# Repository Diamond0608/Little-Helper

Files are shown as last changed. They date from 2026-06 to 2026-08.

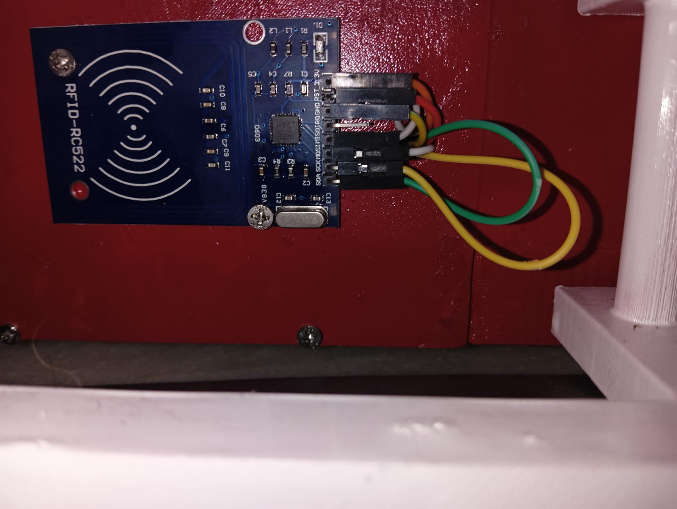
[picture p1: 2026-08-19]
Photos/WhatsApp Image 2026-08-15 at 8.00.09 PM.jpeg

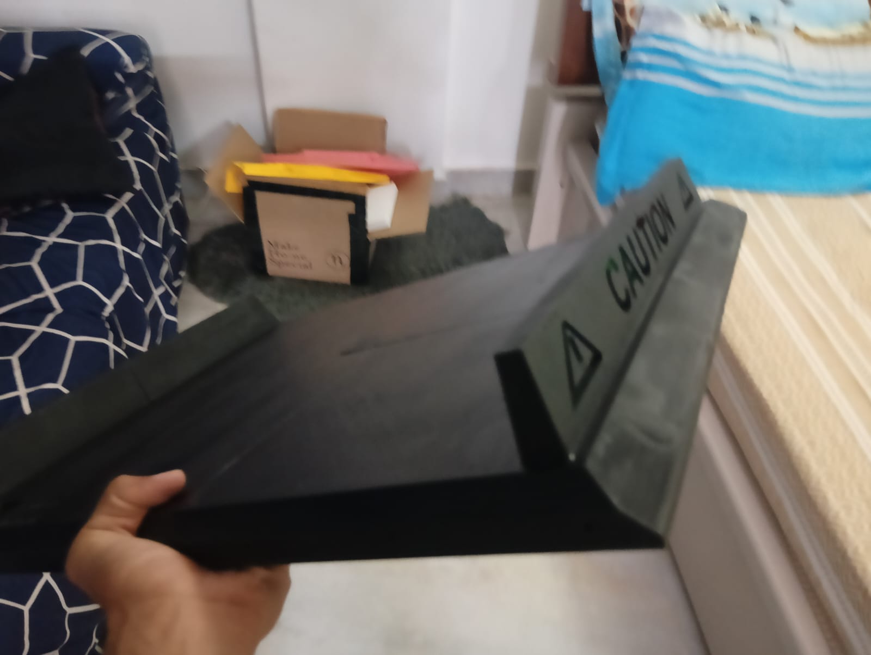
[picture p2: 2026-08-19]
Photos/WhatsApp Image 2026-07-06 at 4.40.42 PM (2).jpeg

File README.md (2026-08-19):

# LITTLE HELPER:
## DOCUMENTATION
<p align="center">
  Littlehelper3
  &nbsp;
  Littlehelper
  WhatsApp Image 2026-08-17 at 5 44 37 PM
  WhatsApp Image 2026-08-17 at 5 44 32 PM
</p>

## Basic Questions and Overview:

### What is Little Helper?

Little Helper is a track based 4wd bot that is capable of  moving around with a giant box on top of it so that teachers can carry books and papers, although it could be used for other purposes as well! As of right now it is controlled via a PS3 controller (you could also use a phone to control it if you tweak the code). I plan to eventually add autonomous capabilities but that is not currently available.
You can find a demo of the bot here: https://youtu.be/gsAc9kgTfto
<p align="center">
  WhatsApp Image 2026-08-17 at 5 44 36 PM
</p>

### Why did I make this project?

A while back after a robotics competition called the National Robotics League, a teacher saw our robot moving blocks around and jokingly asked, could you make it move the textbooks from class to class? We laughed it off, but when I was preparing an idea for Fallout - a Hack Club program, I thought why not actually do that? I love building bots that can drive and it would actually be usefull. (Note this project was submitted to Hack Club's Beest Program, not fallout).

### Use case:
The bot has an A3 sized box on top and a set of tank tracks that help move it, but the bot could very easily be retrofitted to other purposes as well. For example an all terrain bot would also be a valid use case due to the tank tracks. The tank tracks also make it easy to climb stairs or other unusual surfaces (keep in mind the stairs can't have too much height), however, the current version of this bot is unable to climb stairs due to the front plate being too long but I am working on making a new version of the bot that has a much better design, the motors I've used are highly powerful and have really good torque as well, so it would be a good recreation/racing bot perhaps (bear in mind that the bot would be on the heavier side). It could also be used to pull or push objects should you want. (The only limit here is your imagination realistically, the bot is kind off a base to build your ideas!)

### How long would it take me to build this?
The main issue with the building process would be acquiring the parts especially the 3d printed parts, however as for the rest of it, if you're following this guide to the T, a maximum duration should be around 35 hours, since I took that time period to build the project for the first time in R&D without any powertools.

### Can I buy this?
In a way. While the bot isn't available for purchase you can buy the parts and build it yourself! It honestly isn't that difficult even if you have very basic skills in regards to this. Another thing to bear in mind is that this is obviously not a lisenced or approved project, so there's no warranty and should you need regulatory authorisation/permission , you would need to reach out to the appropriate body yourself.

### Is it easy to build this?
Absolutely! The bot is actually quite basic, even the tank tracks are just held on by guiderails and friction. I'm not the most skilled individual so I couldn't make the project too difficult to build, which gives the benefit of an easy to make product. However, obviously it should be noted that this project's target group is enthusiastic tech people/ people getting into hardware.

### Is this all free?
YES! All the materials I've provided are open source, you can use, modify, or distribute them however you like, however please credit me for this build. Infact if you need any help with building this just send an email to me at : alvashlok@gmail.com and I'll try to help you out.

### How expensive is this?
The cost of building it is completely and elaborately detailed in the BOM ( Bill of Materials ) showcased in this repo, but the average cost would be around INR 22697.2 all inclusive, however bear in mind that if you can make the chassis yourself it would be significantly cheaper as all the components except for the chassis and tracks comes to INR 10197.2. The tracks could be DIY'd using bicycle tubing. More details on that are given in the build guide.

## Mapping and Functionality:

The code currently works in the following way: The left stick moves the bot forward and backwards, and the right stick lets you move sideways. The square button activates a buzzer, the O locks the bot, and X toggles the safety mechanism.

### Authentication:
The bot has a 2 factor authentication method- first you scan a keycard on an RFID scanner and then input a pin to gain access. The LCD screen guides you through this process and there are auditory beeps to help as well.
The O button on the controller locks the bot and forces you to authenticate again.
The controller even if connected is practically dead until authentication is completed. The bot starts in a locked state by default when turned on.

### Safety Mechanism:
The bot has an ultrasonic sensor mounted in the front that stops the bot if you are closer than 15 cm from an obstacle. The safety mechanism disables controls at that point and sounds the buzzer. The bot cannot be moved until the obstacle is removed. The safety can be turned off when X is pressed, but this will not work if an obstacle is already in the path of the bot. 

## Suggestions For Use:

1. Firstly if you plan for the robot to move up stairs, keeping CG in mind while loading stuff in the box would help (try to keep the books flat as otherwise not only would it move around but should they fall that may displace the bot). (CANNOT CLIMB STAIRS CURRENTLY)
   
2. The battery life won't be more than an hour (I've not tested this yet but it's an approximate). However installing a battery of higher amperage would be really easy ( Just don't change the voltage or if you do use a step down/step up converter).
  
3. The motor driver already has a very high current draw from the motors since they're 4*1000 RPM Johnson Grade A motors so be wary of installing components that would add to the current draw.

4. To conserve battery life removing components that are unnecessary for your use case is suggested. You can also change the code to tweak the speed of the bot (1000 RPM is the absolute max and the minimum would be whatever you want).

5. People should be aware of the bot's presence wherever you're using it so no one accidentally stays in its path or tampers with it.

6. If exam papers are being carried in the box, lock the box securely.

7. While you are free to use whatever parts you choose, avoid mecanum wheels as they won't fit onto the motors and they can't be used to their potential and as such are a waste of time, since it isn't possible to move sideways etc when using tracks which is the main point of mecanum wheels. Also the wheels may not grip the tracks well.

8. If you want to not use code and have a transmitter/receiver and want to save on parts, you could use an ESC to control your motors with a transmitter and receiver, however you would still need to keep an ESP for the other electronics, and there would be no scope for making the bot autonomous after this.

## The CAD File:

The CAD file can be found in this repository as both a STEP file and a f3d file ( I made the model in fusion ). 
<p align="center">
  Littlehelper5
Littlehelper7
</p>

### Basic Suggestions:

Wherever there are holes with fasteners like screws placed inside, I would recommend drilling the holes with a handhed drill if you have one available to you. If you don't have the access to one however, you can 3d print the part with the hole as a part of it, or as a DIY method that I sometimes use you could heat a sharp metal rod like a small poker used for melting marshmellows/making corn on the cob and then carefully make the hole where you need to (you may not get a tight fit or threading with this method so you may have to add nuts). All the screws are either M3 or M5 to make the process of building easier. IMPORTANT: This is designed to be changeable the motor driver holes I have provided should be adjusted to appropriate dimensions unless you're using the same motors. Similarly adjust all other mounts.

Something to note is that I did not add any spacers between the components and the plastic chassis in the CAD file, however, it's important to do that. Plastic spacers can be 3d printed or bought online as well.

While the CAD file does have 3d wiring, that is more to serve as a reference, there is no gaurantee that it will be accurate and as such please refer to the schematic diagram instead when you're doing the wiring.

Something else to note is that care should be taken while attempting to 3d print. If a part is too big for your 3d printer, I would suggest printing it in pieces and using the adhesive - Metlock 743 which practically makes it one component ( but be very careful with this adhesive as it is incredibly strong and even a drop bonds the plastic together permanently and you should wear a mask and safety goggles incase you see fumes from the plastic (also make sure that you aren't making some kind of toxic fume)). You could also CNC the chassis or make it from foamboard, the CNC version will be heavier however and the foamboard version would be weaker.

Also the tracks while modelled aren't designed to be 3d printed. Tracks should be made of a material like rubber for optimum grip, 3d printing it wouldn't work. I've also not modelled the linking mechanism well enough that you could take 1 link from the cad and just attach it to other links, you would have to glue it together.

Something very important is resizing the power button as per the dimensions of the one you purchase (if theres a large size difference) this has to be a 3d printed hole (you could make the hole yourself if you have the required power tools).

### General Info:

The CAD file has every component and body named for ease, some components/bodies are connecting wires and as such they are named with the origin and destination. This notation is important to note: BR- Back panel Right side, BL - Back panel Left side, FR - Front panel Right side, FL - Front panel Left side, LF - Left panel Front end, RF - Right panel Front end, LB- Left panel Back end, RB - Right panel Back side.

The hinges for the box are 3d modelled but they SHOULD NOT be printed, purchase those from a hardware shop, these hinges are not designed to actually work. I'd also suggest changing the text present on the chassis and box since they're highly customised to me, so it would make sense to change it to something that you want. You could use the timeline feature to find where I wrote the text and just change the text and the extrude should catch up after that operation is done. 

I know it sounds stupid to mention it but please don't try to 3D print any of the wires or electronic components either. 

There are a few joints that can be animated through the relationship page as well : The wheels rotate, the lid of the box opens and closes, the lock for the box opens and closes, and a few of the nuts also rotate.

The placement of most components in the CAD file is genuinely arbritary, you could change it as you please (Obviously would have to change the wiring and mounting points appropriately).

## Code:

The code can be tweaked however you want. Especially do change the configuration for the controls and how you connect your controller (you could keep the same controls if you wish but the controller connection won't transfer).

The code can be uploaded to the ESPs via Arduino IDE. Just make sure you select the appropriate port and board in the board manager, and ensure you have all the required modules installed and all the needed drivers. 

Its also possible to upload the code via VSC if you use PlatformIDE or other such extensions, so if that's something you want to do that is also possible.

There are 2 code files present, one for the ESP32 and one for the ESP8266, keep in mind that I personally AI generated this code and did not make it myself.

<p align="center">


</p>

## Building the Project: 

If you are using self-tapping screws note that the screws can get really hot as you drive them into the bot. I really recommend making the holes yourself with a drill. Note that I did the following tasks in a different order, so the photos may not match the instructions perfectly, in that case please follow the instructions instead of the photos. More photos of what I built can be found in the photos folder of this repo.

1. To start with refer to the BOM and ensure you have all the parts you require. ( You could start building with only some of the parts and adding parts as and when they come as well but workflow would become worse ).

<p align="center">


</p>

2. Step one would be to take your side panels and attach the motors to them. The motors have 3 holes in an L shape which can be matched to the side Chassis. Orient it in a way such that the motor shaft passes through the hole in the same way that in passes through on the opposite side (avoid difference between the sides since that would make the tracks uneven). 

<p align="center">
WhatsApp Image 2026-07-12 at 12 02 51 AM
</p>

3. Once that is done, attach the guidelines as per the screw holes at the center of the side panel. ( For the guidlines there's only a small surface area where there is a contact between it and the panel. 

<p align="center">
WhatsApp Image 2026-07-16 at 5 26 31 PM (2)
</p>

4. Next take the RFID reader, LCD screen and Numpad and place and secure them in the appropriate positions on the side panels. Note that the numpad isn't secured by screws as it has no scope for that due to its thickness and material. The numpad comes with adhesive on the back and it should be placed on the side panel.

<p align="center">
WhatsApp Image 2026-07-13 at 4 38 29 PM (2)

</p>

5. Take the battery and place it in the battery holder (if you changed the battery obviously change the battery holder as well unless it's the same configuration). Secure the cover as well. In my CAD file there is a canvas showing a fire hazard, I would suggest making a marking similarly whether with a marker or a sticker, or 3d printing an imprint or sticking a sheet of paper. 

<p align="center">
WhatsApp Image 2026-07-19 at 1 47 04 PM
</p>

6. Take the bottom panel and attach the battery holder (and the buzzer holder if that was printed seperately).

7. Attach the side panels on both sides to the bottom plate.

8. Now take the wheels and place them on the motor shafts such that the tire treads all point in the same direction and the hole on the tire for the bolt overlaps with the hole on the motor. Place the m3 bolt inside and secure it tightly (the wheels should not shake or come lose). A nut isn't needed for this bolt as the motor shaft has threading.

<p align="center">
WhatsApp Image 2026-07-14 at 4 28 41 PM (1)
</p>

9. Now comes the part that differentiates the bot from other regular 4wd bots. Take the purchased track chain and place it over the two tires on a side. These tracks have removable links, so add or remove the links to tension the track as tightly as you can. Remember that there is nothing holding the chain there except friction. So tighten it as much as you can without risking the chain snapping.
9.1 If you want to make the tracks yourself, simply purchase any regular bicycle tube and cut off the part where the nozzle is present. Once that is done you can wrap it around the wheels and adjust the length until its a very firm grip, but not firm enough that it may snap or is bending the wheels or motors (be very careful about this, you have to get an ideal tensioning). Then mark and cut the track and glue the ends together and mount it securely.

<p align="center">
WhatsApp Image 2026-07-16 at 5 26 31 PM (1)
</p>

10.  Great! Now you have your hollow shell, the next step would be wiring etc, before you close the top or front and back plates so that you can still easily access components. Bring the wiring for the components placed on the side panels through their respective holes. Then place the motor driver, ESP8266, and ESP32 in their respective positions. Attach the ultraonic sensor to the front panel on the mounting plate. Plop the buzzer into its holder as well (Don't attach power button yet).

<p align="center">
WhatsApp Image 2026-08-15 at 8 00 09 PM (1)
</p>

11.  Next refer to the wiring schematic and connect all the components together(except leds). If you don't want the wires coming off you can solder them to the terminals instead of just having the jumper cables. Do not connect the battery or powerswitch yet.

12.  Now would be the stage where I would suggest you upload the code, as you can still test and make sure everything is correct by fixing any issues before you close any panels. (NOTE: DO NOT UPLOAD THE CODE WITH THE BOT ON A TABLE. Sometimes the wheels can spin when you're uploading the code, yes , even if you've disconnected the battery.) Make sure to upload the codes for both the ESPs.

13.  Once that's all done and dusted you can go ahead connect the battery and the powerswitch, but leave the powerswitch dangling somewhere inside the chassis do not secure it in place yet as then you would have to close the top panel.

14.  Switch it on and configure your method of controlling the bot and then make sure everything is running fine, and if not debug.

15.  Now keep all the panels in close vicinity and attach the front and back plates to the side panels.

16.  Attach the led lights to the resistors and cables and wire it appropriately. Then insert the led light into the side plate by pushing it into the led holes till its securely fastened. Now test the led lights.

17.  Take the top plate and attach the box to it (if you are attaching one to carry stuff). Secure it tightly since it moving can affect the CG and make the bot topple down the stairs if it shifts.

18.  Detach the powerswitch and attach it to the top panel and then wire it backk to where it was. Attach the top plate to the side panels.

19.  Paint/add stickers as required.

20.  Drive it around and test it!

### CONGRATS!!!! YOU HAVE NOW BUILT THE BOT!!!

#### Now use your bot as you please. Modify your design as per your testing diagnostics. If you find an easier way to do something or find an issue or have modified your bot, you should try to comment on the repo so that others also benefit from your knowledge.

## NOW GO AND SHOW OFF YOUR BOT!

Some photos:
<p align="center">
Littlehelper11

WhatsApp Image 2026-08-17 at 5 44 32 PM (1)
WhatsApp Image 2026-08-17 at 5 44 33 PM
WhatsApp Image 2026-08-17 at 5 44 33 PM (1)
WhatsApp Image 2026-08-17 at 5 44 36 PM (1)
  Littlehelper9
WhatsApp Image 2026-08-16 at 10 16 43 PM

</p>

# Maintained and developed by : SHLOK ALVA

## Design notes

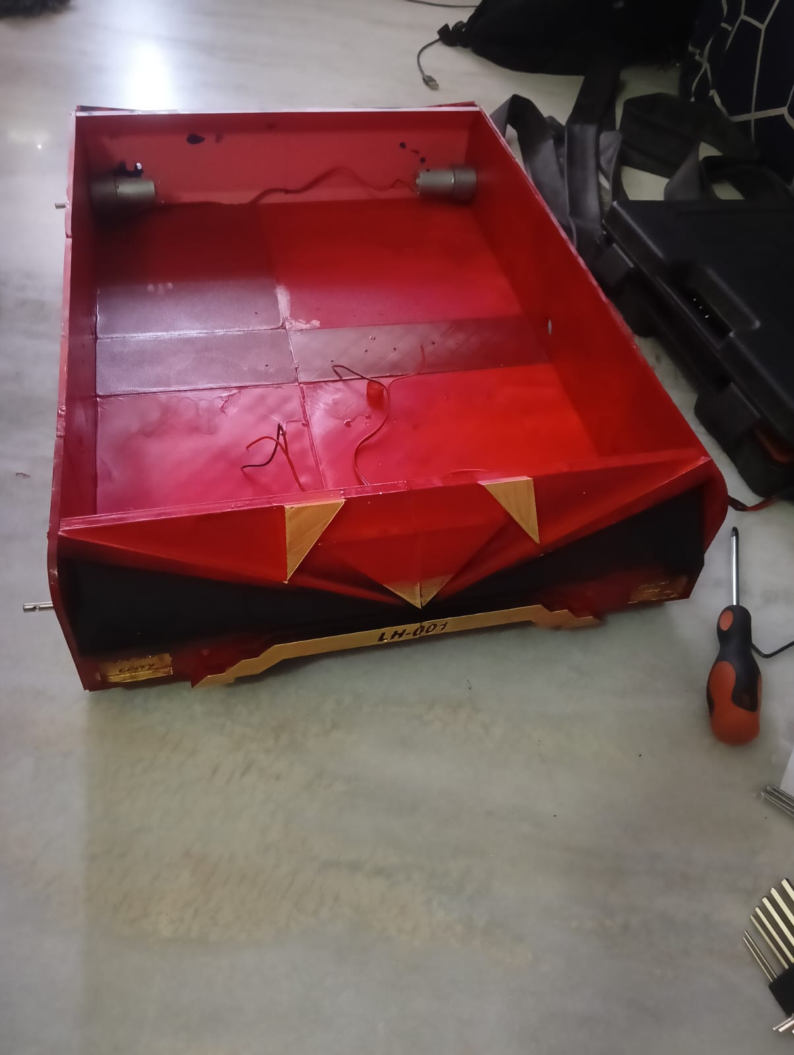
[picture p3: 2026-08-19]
Photos/WhatsApp Image 2026-07-12 at 2.37.22 PM.jpeg

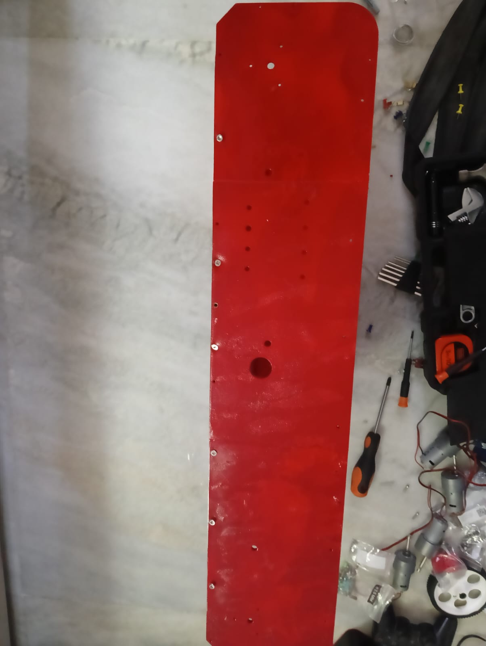
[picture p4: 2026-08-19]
Photos/WhatsApp Image 2026-07-11 at 4.24.16 PM.jpeg

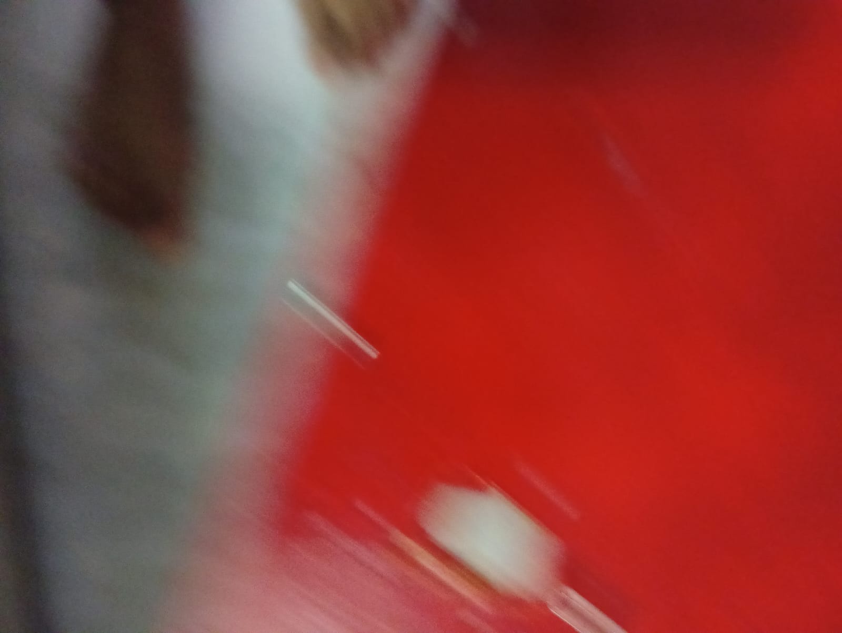
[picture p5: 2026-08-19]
Photos/WhatsApp Image 2026-07-11 at 5.39.20 PM.jpeg

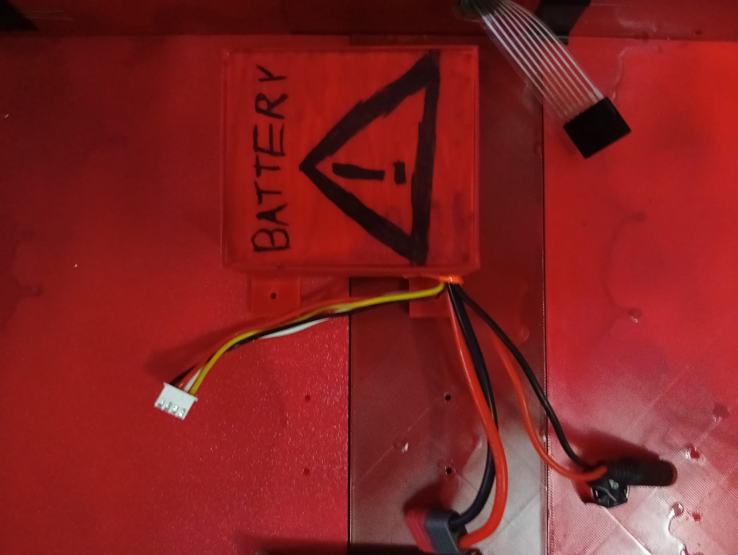
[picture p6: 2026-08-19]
Photos/WhatsApp Image 2026-07-19 at 1.47.04 PM.jpeg

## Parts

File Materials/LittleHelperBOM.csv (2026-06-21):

BILL OF MATERIALS (BOM) for Little Helper:
This is the BOM for the V1 of the file, and as such it does not have autonomous capabilites. The parts listed here can be customised to your preference.
Serial Number | Item Name | Item Description/Link | Price Per Unit | Qty | Total Price (With tax) | Notes:
 |  |  |  |  | 0
CHASSIS COMPONENTS: |  |  |  |  | 0
 |  |  |  |  | 0
1 | Chassis Top Plate |  |  | 1 | 0 | I've quoted a price for 3D printing, it can be CNCd as well / woodworked. Or made out of foamboard (be careful may not be
2 | Chassis Bottom Plate |  |  | 1 | 0 | strong enough to withstand the torque.)
3 | Guide Rails |  |  | 2 | 0 | Exact cost for 3D printing would depend on many factors, I've provided an estimate from printing legion (Hack Club).
4 | Side Panels |  |  | 1 | 0
5 | Front Panel |  |  | 1 | 0
6 | Back Panel |  |  | 1 | 0
7 | Battery Holder |  |  | 1 | 0
8 | Tracks |  | 2500 | 1 | 2500 | Could also DIY the tracks yourself for half the cost using eletrical conduits, bicycle inner tubing and zipties. (More details to come)
 | TOTAL: |  | 10000 | 1 | 10000 | Without tracks
 |  |  |  |  | 0
ELECTRONICS COMPONENTS: |  |  |  |  | 0
 |  |  |  |  | 0
8 | 3S 11.1V 2200 mAh Battery | https://robu.in/product/pro-range-18650-li-ion-2200mah-3s-11-1v-10c-3s1p-with-jst-xh-female-t-connector-female/ | 1649 | 1 | 1649 | Can use a higher capacity battery for a longer life.
9 | Buzzer | https://robocraze.com/products/3-volts-buzzer-small?_pos=3&_sid=2ff08fb82&_ss=r | 14 | 1 | 14 | Buy a passive buzzer instead if you want to be able to change the tones.
10 | LED Light Red | https://robocraze.com/products/3mm-red-led-pack-of-10?_pos=1&_sid=30256fbbe&_ss=r | 1.5 | 10 | 15 | Only 8 are needed but can only be bought in packs of 10
11 | Johnson Grade A 1000RPM Motors DC | https://robocraze.com/products/johnson-dc-geared-motor-12v-1000-rpm-grade-a | 569 | 4 | 2276 | Can change motors but change the wheel to make sure shafts match.
12 | 4.7 kohm resistor | https://robocraze.com/products/4-7k-resistor-pack-of-10?_pos=4&_sid=6e7182c4c&_ss=r | 1.2 | 10 | 12 | Only 8 are needed but can only be bought in packs of 10
13 | RC522 RFID reader/writer | https://robocraze.com/products/rfid-rc522-mfrc?_pos=1&_psq=rfid+rc&_ss=e&_v=1.0 | 89 | 1 | 89 | Only use if you also want to restrict access during operation like me.
14 | SW_SPST (Rocker Switch) | https://robocraze.com/products/rocker-switch-6a-250v-spdt-3-pin-red-led?_pos=3&_sid=4e117ee12&_ss=r | 45 | 1 | 45 | Use good quality wires as they don't come with the component (mentioned)
15 | ESP8266 NODEMCU 12-E | https://robocraze.com/products/nodemcu-esp8266-amica-cp2102-driver?_pos=3&_sid=32cb70c9e&_ss=r | 236 | 1 | 236 | Can use another version just change the wiring and code.
16 | ESP32 NODEMCU XXSR69 | https://robocraze.com/products/esp32-development-board?_pos=1&_sid=abb9eb10e&_ss=r | 425 | 1 | 425 | Can use another version just change the wiring and code.
17 | MDD10A_REV2.0_CYTRON | https://robocraze.com/products/cytron-10a-5v-30v-dc-motor-driver-2-channels | 2699 | 1 | 2699 | If changing this make sure the current draw is handalable(the 1000RPM motors will fry an LN298 motor driver).
18 | 4*4_Matrix_KeyPad | https://robocraze.com/products/4x4-membrane-keypad?_pos=1&_sid=1b5f670d7&_ss=r | 41 | 1 | 41 | Only use if you also want to restrict access during operation like me.Or for an input like class and section for autonomous.
19 | HC-SR04 Ultrasonic Sensor | https://robocraze.com/products/hc-sr-04-ultrasonic-sensor?_pos=1&_sid=cae36d341&_ss=r | 89 | 1 | 89 | Can be removed if you don't want it, I've used it for emergency stopping since it will be run in a school.
20 | I2C_LCD_ADAPTOR | https://robocraze.com/products/16x2-lcd-i2c-interface-adapter?_pos=1&_psq=I2C&_ss=e&_v=1.0 | 53 | 1 | 53 | Can also get an LCD screen with this integrated.
21 | LCD16*2 | https://robocraze.com/products/16x2-lcd-module-green?_pos=2&_sid=d7554cae1&_ss=r | 165 | 1 | 165 | Any LCD screen with 16 pins will do, not a necessary component you can use an app/serial monitor for outputs as well.
22 | LM2596 Buck Converter 11.1-3.3 | https://robocraze.com/products/lm2596-dc-dc-step-down-buck-module-with-display?_pos=4&_sid=535535c18&_ss=r | 109 | 1 | 109 | DO NOT FORGET. YOU WILL FRY YOUR 5/3.3V COMPONENTS.
23 | Wires for switch SafeConnect Nylon T | https://robu.in/product/safeconnect-nylon-t-connector-pair-with-jst-male-in-line-power-adapter-cable/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 | 99 | 1 | 99 | For safety :0
24 | PS3 Controller | https://www.amazon.in/GAMENOPHOBIA-Controller-Playstation-professional-PlayStation3/dp/B09J1BYSQB | 780 | 1 | 780 | Can also use a PS5 controller/phone/anything you want.
 |  |  |  |  | 0
MISCELLANEOUS COMPONENTS: |  |  |  |  | 0
 |  |  |  |  | 0
25 | Tyre 20mm*100mm | https://robocraze.com/products/10-x-2-cm-gear-motor-robot-wheel-tyres-for-6-mm-shaft-geared-dc-motor-4-pieces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 | 52.25 | 4 | 209 | This is a link for 4 tyres, DO NOT ORDER 4 SETS OF TYRES.
26 | A3 Box For Books | https://amzn.in/d/0fPFYW2t | 899 | 1 | 899 | Can remove this if no need of transport, can also customise the box.
27 | M3 Screws 10mm | https://onlyscrews.in/products/m3-x-10mm-hex-allen-csk-high-tensile10-9-black-oxide-screw-dia-3mm-length-10mm | 1.8 | 60 | 108 | Recommended to just get a screw kit/set. The screws are also purchasable at a local hardware shop instead of online.
28 | M5*35mm Hex Head Bolt | https://onlyscrews.in/products/m5-x-30mm-hex-allen-csk-high-tensile10-9-black-oxide-screw-dia-5mm-length-30mm-1 | 2.8 | 4 | 11.2 | If using nuts, nylon is good since it will be a very tight lock, however, the nut gets worn and less effective with each use.
29 | M5 Hex Nut | https://onlyscrews.in/products/m5-nyloc-nuts-mild-steel-with-zinc-plating-dia-5mm | 1.2 | 4 | 4.8 | Use self tapping screws if you don't have a threaded hole.
30 | M3 Screws 4mm | https://onlyscrews.in/products/m3-x-8mm-hex-allen-socket-head-high-tensile12-9-black-oxide-screw-dia-3mm-length-8mm | 3 | 28 | 84
31 | M3 Hex Nut | https://onlyscrews.in/products/m3-nyloc-nuts-mild-steel-with-zinc-coating-dia-3mm | 0.9 | 4 | 3.6
32 | M3*30mm Screw | https://onlyscrews.in/products/m3-x-30mm-hex-allen-socket-head-ss-304-screw-dia-3mm-length-30mm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 | 6 | 4 | 24
33 | M3*25mm Screw | https://onlyscrews.in/products/m3-x-25mm-phillips-csk-ss-304-screw | 2.4 | 8 | 19.2
34 | M5*16mm | https://onlyscrews.in/products/phillips-csk-m5-x-16mm-pack-of-20 | 2.4 | 16 | 38.4
 |  |  |  |  | 0
SUGGESTED TOOLS (INCLUDING SOFTWARE): |  | (Not calculated into cost) |  |  | 0
 |  |  |  |  | 0
35 | Screwdriver Phillips Head |  |  | 1 | 0 | As per your convenience choose whatever tools you require.
36 | Allen Key Set |  |  | 1 | 0
37 | Soldering Iron |  |  | 1 | 0
38 | Drill (Should work on plastic) |  |  | 1 | 0
39 | 3D printer/CNC/Woodworking tools |  |  |  | 0
40 | Arduino IDE |  |  |  | 0
41 | Modules specified in code |  |  |  | 0
42 | Some 3D CAD software |  |  |  | 0
43 | Wire strippers and cutters |  |  |  | 0
 |  |  |  |  | 0
 |  | Total Price : | INR | 22697.2

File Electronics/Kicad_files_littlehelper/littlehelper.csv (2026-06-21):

Reference | Qty | Value | DNP | Exclude from BOM | Exclude from Board | Footprint | Datasheet
BT1 | 1 | 3S 11.1V 2200 mAh Battery |  |  |  |  | ~
BZ1 | 1 | Buzzer |  |  |  |  | ~
D1,D2,D3,D4,D5,D6,D7,D8 | 8 | LED |  |  |  |  | ~
M1,M2,M3,M4 | 4 | Johnson Grade A 1000RPM Motors DC |  |  |  |  | ~
R1,R2,R3,R4,R5,R6,R7,R8 | 8 | 4.7kohm resistor |  |  |  |  | ~
RFID1 | 1 | RC522 RFID reader/writer
SW1 | 1 | SW_SPST |  |  |  |  | ~
U1 | 1 | ESP8266
U2 | 1 | ESP32
U3 | 1 | MDD10A_REV2.0_CYTRON
U4 | 1 | 4*4_Matrix_KeyPad
U5 | 1 | HC-SR04 Ultrasonic Sensor
U6 | 1 | I2C_LCD_ADAPTOR
U7 | 1 | LCD16*2
U8 | 1 | Buck Converter 11.1-3.3

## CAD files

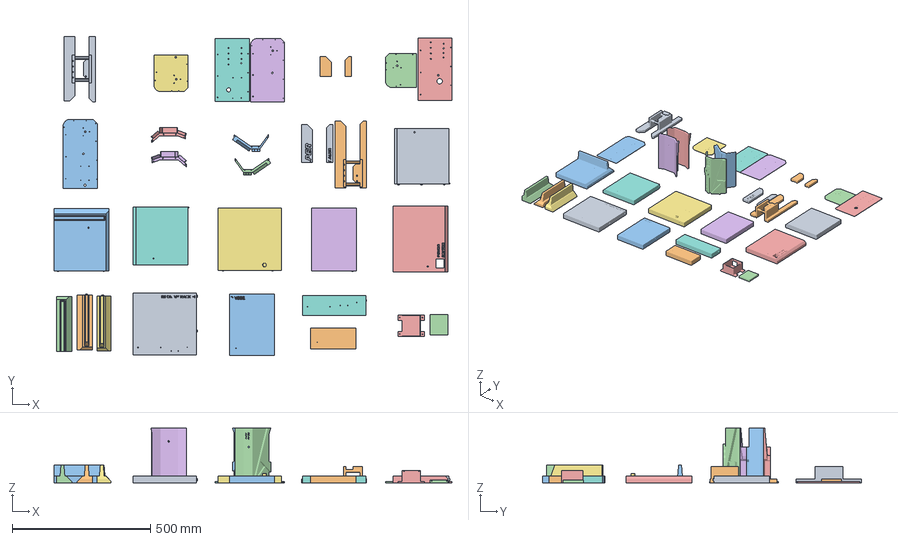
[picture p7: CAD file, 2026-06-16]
CAD_Work/BIG CHONKER.3mf
1441.5 x 1155.0 x 198.5 mm
guiderails.step_B_B_A
guiderails.step_B_B_B
Lpanel.step_B
Lpanel.step_A_A
Lpanel.step_A_B
Side Panel Chassis R.step_B
Side Panel Chassis R.step_A_A
Side Panel Chassis R.step_A_B
guiderails.step_A_A
guiderails.step_A_B
Rear Panel Chassis.step_A
Rear Panel Chassis.step_B
Front Panel Chassis.step_A
Front Panel Chassis.step_B
Chassis Top.step_B_A_A
Chassis Top.step_B_A_B
Chassis Top.step_B_B_A
Chassis Top.step_B_B_B
Chassis Top.step_A_B
Chassis Top.step_A_A_A
Chassis Top.step_A_A_B
Base Chassis.step_B_A
Base Chassis.step_B_B
Base Chassis.step_A_B_A
Base Chassis.step_A_B_B
Base Chassis.step_A_A_A
Base Chassis.step_A_A_B
Battery holder cover.step
Battery Holder.step

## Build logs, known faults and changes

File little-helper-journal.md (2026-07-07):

# Little Helper — Journal Export

- Exported at: 2026-06-16T11:57:51Z
- Project ID: 4068
- Entries: 34

## Entry 1
- ID: 10608
- Author: Diamond_0608
- Created At: 2026-05-31T08:07:21Z
**NOTE:**  54min tracked
2 recordings
### Content

So to start out with my build, I first decided to 3d model the box in which the teachers can place the books and then 3d animate it. I couldn't manage to design exact hinges but I made something that was understandably a hinge. I made a latching mechanism since if the bot is climbing stairs the books falling out would obviously be :(. I made the size of the box A3 with enough height for all the textbooks and notebooks they may carry between classes as well. (The box could be 3d printed except for the hinges as long as you either print it in pieces and use plastic adhesives or just bought from a store like an icebox or made from foamboard with the hinges  bolted in (use thick foamboard else the box may tear from the bolts/ the weight). The mechanism to attach the box to the bot will be constructed after I make the bot. I'm not the best at 3d cad design so this was the best I could do. I didn't want an open box because then teachers can have privacy if theyre transporting papers and nothing can fall out as well. The A3 size was chosen since I thought that's the biggest size I've personally seen a teacher carry around my school. The hinges were particulary hard for me to cad design since I'm not good with designing parts that actually fit together, I'm more of a build it in person with cad as a visualisation tool person. The animations helped make sure it all fits together right and moves in the right way and the dimensions and spacing are right. TLDR: made box for the books :D


### Recording Links

- https://lookout.hackclub.com/api/media/2316cc98-ef85-48a0-90f8-a4a26a0e4e4c/video.mp4
- https://lookout.hackclub.com/api/media/e30a812a-4860-4b0b-bdf9-6acab6da91be/video.mp4

## Entry 2
- ID: 10915
- Author: Diamond_0608
- Created At: 2026-06-01T15:50:19Z
**NOTE:**1h 16m tracked
2 recordings

### Content

What I did today was I started with the CAD work for the actual chassis, wheels and tracks for little helper. I made a base plate, replicas of the Johnson Grade A 1000rpm motors I'll be using with their L shaped mounting method and the top plate, track link and wheels. I inserted the self tapping screws that attach the side plates to the base and top as well and the m3 screws that attach the wheels to the motors. The motors and wheels can be purchased along with the nuts and bolts and tracks and the rest can be 3d printed, people can even cnc the chassis if they want to avoid it warping from the torque. People can even use different motors if they want but they'd have to change the design. I had to cad one of the hex nuts myself as well since I couldn't find it. I'll do assembly of all of it together once all the parts are ready. I spent a long time deciding how to climb stairs in this bot and I decided on tracks since its the simplest way and the tracks work by a 4wd system where the friction pulls the tracks and guide rails( I still have to cad the rails) hold the tracks in place. It's a very crude track system but it's the best I can do. 





### Recording Links

- https://lookout.hackclub.com/api/media/1c1d3db5-312e-4cee-bad0-0ea3d08421ad/video.mp4
- https://lookout.hackclub.com/api/media/7691c1e3-7647-4ff7-88da-bb745cf0670b/video.mp4

## Entry 3
- ID: 10943
- Author: Diamond_0608
- Created At: 2026-06-01T17:33:07Z
**NOTE: **50min tracked
1 recording
### Content

What I did now was I made a 3d version of the battery that I'm using (11.1V 3s Liion 2200mah battery) and of my esp8266 and small electronics components (red led light for warning and buzzer) and I finally made the tank tracks by first making a small piece thats going to be the section and then tracing out a path and making a pattern and it actually ended up looking pretty sick. Doing the design of the tracks helped me realise i miscalculated pretty big and I need 4 of the track sections im ordering and not 2 so that would have been a very big oopsy. The next steps are obviously adding more parts and assembly but atleast its starting to come together and look like a track based robot. 








### Recording Links

- https://lookout.hackclub.com/api/media/f8cbb99b-862d-46a5-8948-2a92dc5b6239/video.mp4

## Entry 4
- ID: 11098
- Author: Diamond_0608
- Created At: 2026-06-02T10:10:57Z
**NOTE: ** 54min tracked
1 recording
### Content

What I did today was I added smaller electronics like the RFID, numkey, motor driver, power switch and then I animated the joints between the motor and wheel and brought the tracks into place. I tried animating the tracks to link to the wheel but I was wildly unsuscessful there. I brought the bolts into place as well for the motor. I decided to just ditch animating the tracks for now (in the CAD model you will see a gap between the tracks and the wheel just ignore this and make sure to tension the track as much as possible without risking it snapping.) I was trying to bring the side plate to the main body when I realised two things, I completely forgot to add the guides and the side plate is way too short. But that is a problem I'll fix in the next journal. As always this project seems way out of my league but we shall keep trying.





### Recording Links

- https://lookout.hackclub.com/api/media/f7700b66-6f0c-48c4-9131-254c8c62c84c/video.mp4

## Entry 5
- ID: 11421
- Author: Diamond_0608
- Created At: 2026-06-03T17:22:25Z
**NOTE:** 1h 9m tracked
2 recordings
### Content

Today I did some pretty basic and unremarkable work. I mostly worked on creating joints between components and fixing the sizing issue that was present for the side plates. I realised that the side plates were too thick to not hit the tracks so I reduced the thickness. I also made the guide rails for the tracks so that they don't fall off since they're purely friction based tracks with no binding mechanism. I added supports for the guide rails and made them a part of the side plate itsself to avoid complicating it. I started with the front and back plates and joining the box for the books to the top plate as well. I didn't achieve nearly as many hours as I wanted to today and I have to absolutely lock in if I want to make it to fallout.




### Recording Links

- https://lookout.hackclub.com/api/media/c40d97ba-7fd9-488d-80fa-bb69fea1a167/video.mp4
- https://lookout.hackclub.com/api/media/72136b36-6ff4-4c40-9c01-cf7386dc44d7/video.mp4

## Entry 6
- ID: 11577
- Author: Diamond_0608
- Created At: 2026-06-04T09:38:03Z
**NOTE:** 1h 2m tracked
1 recording
### Content

So today to start off the day, I first added the bolts and nuts to hold the box to the top plate and then I started changing the appearance and material of all the components to make it more accurate and for aesthetics. I also started making a battery holder and added little terminals to the motors. I made the wheels resemble what they look like in real life as well. And that's about it really.





### Recording Links

- https://lookout.hackclub.com/api/media/11218c43-10e1-4c36-a37a-e58e14d78fc0/video.mp4

## Entry 7
- ID: 11628
- Author: Diamond_0608
- Created At: 2026-06-04T15:30:59Z
**NOTE:** 
1h 45m tracked
2 recordings
### Content

What I've done now has actually been really productive, I worked on the battery holder and fixed some joints and decals and designed the battery holder with all the mounting screws decals and a hole for the wiring as well. The more exciting part though is what I did after, today I finally got rid of that ugly looking threading on the tires and replaced it with actual tire tread and that honestly looked amazing. I also changed the side plates so they actually have a design element to them and are no longer just flat rectangles now. On the guide rails as well I added some text. The most drastic change in terms of apppearance is the front plate which has gone from a flat rectangle to an actual really cool design that I'm pretty proud off, I learnt how to use the emboss tool just for that. I also added materials again especially rubber to the tracks and tires. I put some text on the front as well as a kind off joke number plate. The design actually looks pretty alright, and despite the fact that to most it probably still looks abysmal I'm suprised I managed to get this far. Hopefully the rest of my days stay this productive. Shenzen here I come. For tomorrow I'm going to work on the back plate and some more aesthetics as well as moving the electronic components in, trying to see if I can actually make links for the tracks and who knows what else.








### Recording Links

- https://lookout.hackclub.com/api/media/071dd335-b6cb-4861-a49b-0823e9f8e2cd/video.mp4
- https://lookout.hackclub.com/api/media/069b3031-1463-4da3-94f8-49d697bbe4a3/video.mp4

## Entry 8
- ID: 11664
- Author: Diamond_0608
- Created At: 2026-06-04T17:44:02Z
**NOTE:** 
57min tracked
1 recording
### Content

To sign off for the day I made the backplate design, similar to the front and with its own text as well. I then moved and attached the front plate to the side plates with screws and I also learnt how to use the activate component tool and how to switch back to be able to work on the project easier. It was a long tiring and productive day, and hopefully tomorrow will be more of the same.






### Recording Links

- https://lookout.hackclub.com/api/media/3f87cb39-4841-4e93-babf-bca5faaf5691/video.mp4

## Entry 9
- ID: 11805
- Author: Diamond_0608
- Created At: 2026-06-05T09:51:04Z
**NOTE:** 
2h 6m tracked
1 recording
### Content

To start today first I updated the guide rails to make them look better by adding some detailing. I joined the back plate to the main chassis as well with bolts and all which was difficult because of all the overlap. I resized the bottom plate a bit to accomodate the back plate as well. All of the fasteners I've used so far have been placed in holes with modelled threading as well. Then I attached both side plates to the bottom plate of the chassis with screws as well. I also remodelled the hinges of the box completely since they looked horrible before. I added some text to the sides of the box as well for some design elements.









### Recording Links

- https://lookout.hackclub.com/api/media/560ec698-c1e4-4351-bb05-803bb20ffcd1/video.mp4

## Entry 10
- ID: 11860
- Author: Diamond_0608
- Created At: 2026-06-05T15:45:38Z
**NOTE:** 1h 55m tracked
1 recording
### Content

What I've done now is I've made the top cover look better and then moved the entire top with the box to the main chassis which was incredibly frustrating since it didn't want to move together no matter what I tried, and it put my screws in the middle of nowhere miles apart (shown in photo) and moved parts into the middle of the box for some reason as well which was ridiculously frustrating so I just remade the parts. The infinite amount of parallax error also drove me absolutely nuts. After that, once the top plate was adjusted properly and bolted in I started moving the electronic components in, and screwing them in until I realised that in my infinite wisdom I didn't leave any space for the RFID and numkey. So I had to chop the guiderails on one side to fix this, which is a bit odd but is my best option all things considered. After fixing this and a few other misconfigured joints, I also had to redo the canvases since they were seen across the project, weren't selectable and didn't move with the objects. I also added a caution plate on the front. Fusions view movement tool also keeps bugging out and I think I might lose my mind. 








### Recording Links

- https://lookout.hackclub.com/api/media/3d2d8093-5481-4213-81ce-ab8733da4e92/video.mp4

## Entry 11
- ID: 12019
- Author: Diamond_0608
- Created At: 2026-06-06T09:17:38Z
**NOTE:** 
1h 50m tracked
1 recording
### Content

To start off the day, I first increased the height of the guide rails since I realised that they weren't really guiding anything, and checked that the bottom rail wasn't touching the ground. Then I redesigned the leds a bit and put them in set placed holes around the chassis. Then I fixed the RFID positioning and some faulty joints for that. I've finally reached the unfortunate point where fusion lags especially if I try to change old components so that's a bit annoying, and hopefully I finish the CAD work soon. I had to stop recording for a while as well since I was just waiting between clicks to delete the rfid linkages cause I had to redo that completely. I also added a little holder for the buzzer to sit in (didn't seem necessary to make a locking mechanism for it so it just sits in place). Added a power button to the top as well. I fixed some mismatched spacing on the bottom plate as well. I then started making the connecting wires between the motors and the motor driver. The level of detail I'm trying to add is making my computer genuinely tweak. I tried to join each connecting wire to the motor driver with smaller copper wires but after getting a horrible result and incredible lag with one soul sucking wire I decided only to keep 1 connected properly and the rest differently. Next up would be finishing the wiring for the rest of the parts and some final polish work cause I'm genuinely done with this CAD work.










### Recording Links

- https://lookout.hackclub.com/api/media/e2cd16e9-7e1f-4672-8e29-4c4928700da7/video.mp4

## Entry 12
- ID: 12042
- Author: Diamond_0608
- Created At: 2026-06-06T14:16:49Z
**NOTE:** 3h 2m tracked
1 recording

### Content

I started off by finishing the motor wiring into the motor driver, then I worked on getting the power switch, battery and motor driver connected. In my attempt to make a good battery wire, I completely crashed my fusion ( thank god for recovery files ). I've never made any splines in 3d so I had no clue how but a few crashes and recovery files and a whole lot of frustration and tweaking later I finally made a whole one wire for the battery connector. This would have been a very usefull tool to have known for the motor driver wires but alas. I connected the battery wire to position of the battery and then made a connector head for it and detailed that. Was all that detailing time worth it? I damn well hope so. I also fixed another missing screw.  I connected the button to the motor driver as well which was a lot easier since I had already learnt the trick.
I then made a little resistor for the led lights since thats a very important component not to forget in the build. Then I added a way to attach the sideplates with the guidelines to the main chassis instead of printing it as one part since it's pretty big. I also fixed some placement issues since for some reason my files placements got messed up. I also made some holes for wires for the rfid and numkey ( The rfid will be used for teachers to scan their access card and the numkey to enter the classroom.).







 


 


### Recording Links

- https://lookout.hackclub.com/api/media/25db5fb9-9dc3-42e4-a800-040ec20ce161/video.mp4

## Entry 13
- ID: 12298
- Author: Diamond_0608
- Created At: 2026-06-07T15:38:21Z
**NOTE:** 1h 52m tracked
1 recording
### Content

To start out today I moved the resistors to the LED lights. I then made some pin headers for the ESP8266 and the motor driver and made the connections between them as well. Then I tried to move the tracks so they actually sat on the tires instead of magically levitating. I first tried to do this by changing the spline sketch over the wheels until after doing that I realised that it was the position of the first link that affected that so I in essence wasted all my time. Fusion also keeps randomly closing when it lags, which is becoming very ominous. I also changed how the tracks look by adding the actual links between the individual chain pieces to make the tracks slightly better. I had to readd some resistors since for some reason half of them just vanished and kept dissapearing. I connected all the leds to the esp as well after checking that it wouldn't fry the esp. Next up I have to wire the ground for the leds, make an ultrasound sensor and place that and then I have to wire the rfid, numkey, and the ultrasound and code it all as well which is a part I'm not particularly looking forward to rn. What's really cool though is you can see my CAD skills improving through this project.









### Recording Links

- https://lookout.hackclub.com/api/media/076d1f5b-c093-45d2-949b-db7d3b4e721c/video.mp4

## Entry 14
- ID: 12350
- Author: Diamond_0608
- Created At: 2026-06-07T18:46:46Z
**NOTE:** 1h 23m tracked
1 recording

### Content

To sign off for the night, I first made the ultrasound sensor and a plate for it and attached it to the front, which doesn't look the best but since it's necessary there isn't really a choice. Then I made the wiring for the -ve wires for the LEDS which I had to do twice since it didn't work the first time around. I also realised the reason everything kept getting messed up is I accidentally keep moving components like the base plate :D. And that's it for tonight.






### Recording Links

- https://lookout.hackclub.com/api/media/551a54f3-61f1-4485-bc2c-7a81e3febda6/video.mp4

## Entry 15
- ID: 12541
- Author: Diamond_0608
- Created At: 2026-06-08T17:03:28Z
**NOTE:** 26min tracked
1 recording
### Content

I was a bit busy today so my logged hours ended up coming up under my goal. I started out with connecting the buzzer to the ESP's ground and GPIO pin. Fusion and my laptop are really struggling now with the number of components so after the wiring for the rest of the components and the aesthetic design updates I'll stop my CAD work. Next I did the wiring for the RFID (Didn't finish it though). In the middle of all of this lookout started tweaking out as well which was not helping at all. Not a very productive day but what can you do.



### Recording Links

- https://lookout.hackclub.com/api/media/3260f2b1-3842-491b-83b6-787e9bf4f18d/video.mp4

## Entry 16
- ID: 12749
- Author: Diamond_0608
- Created At: 2026-06-09T12:22:06Z
**NOTE:** 1h 8m tracked
1 recording

### Content

Today, I resumed with the rfid wiring but realising that I couldn't  make the RFID sketch for the wires work I decided to redo the sketch one by one. The lag is honestly becoming incredibly frustrating. Every single new action is starting to lag out fusion and I can't pause lookout everytime since its 10s of lag and I loose a minute of recording but I realised I could just hide most components and that may help a little. Something else that I really need to figure out is the automation aspect, as until now I've been thinking of rotary encoders/hard coded paths but that seems like poor implemenation but I'm absolutely unfamiliar with LIDAR, and I don't want a line follower. The wiring in CAD will act as a very basic reference but the wirings from here absolutely shouldn't be followed (I'll make a schem diagram that should be used instead). I also realised I should 100% rename all components and bodies since I spend forever just looking for it in the browser and anyone trying to recreate it will face the same issues. I also realised while connecting the RFID that I don't have enough pins, so I decided that I'll connect a slave arduino uno as well. 



### Recording Links

- https://lookout.hackclub.com/api/media/99cb163f-acfa-44fd-a122-ead3eca873f5/video.mp4

## Entry 17
- ID: 12778
- Author: Diamond_0608
- Created At: 2026-06-09T15:43:41Z
**NOTE:** 1h 43m tracked
1 recording
### Content

I started making an arduino Uno model as a slave to the esp 8266. I've used an esp8266 and an arduino since that's what I have, but people could use rasberry pis, arduinos,esp32s or whatever suits them better. I also realised that an led/lcd display is pretty much necessary for any info to be displayed. I also made an LCD screen model and wired the numkey to the arduino. I even modelled the cable from the numkey to look like a proper cable and gave all the pin headers to the arduino and connected the arduino to the esps VIN pin. The components keep shifting and causing alignment issues and I have no clue what to do with that at this point so for the time being I just have to ignore it. Everytime I think I'll be done with the CAD soon, I realise I have something or the other to add. I think something I'm also going to do is I'm going to make the bot manually controlled initially, and if feasable add capabilities for autonomous navigation. The wiring to me is by far the hardest part of the CAD work.
Unfortunately my fusion shut and since I hadn't saved literally all the work I did in this log just vanished infront of my eyes. Definitely the hardest day to power through yet. Redoing all of the work is just heartbreaking.





### Recording Links

- https://lookout.hackclub.com/api/media/5e5bdd33-792d-4052-a512-6f83feecf50a/video.mp4

## Entry 18
- ID: 13032
- Author: Diamond_0608
- Created At: 2026-06-10T15:52:50Z
**NOTE:** 
1h 39m tracked
1 recording
### Content

To start off for today, I first had to surmount the tragic task of redoing all the work that was lost yesterday in the fusion crash. I realised my C drive was completely filled so hopefully giving that more space and constantly saving my files is going to save me now. I had hoped that having done it before it would turn out better than previously and in faster time, but this run had its own complications.I really can't wait to start building, I feel like skipping the coding and diagram schematics so bad. I also decided to ditch the Arduino Uno and keep a ESP32 as my device with an 8266 as secondary. I realised I completely forgot to put spacers for any of the electronic components, so that's something I'll have to include in the readme. For some reason Fusion is failing to make recovery files, so I better keep saving and praying nothing goes wrong. I was thinking of just using the same spline to make lofts for wires but the wires start looking so identical that it loses its charm and it doesn't always work. The messy wires are kind of like perfection in inperfection. I just made the base plate unselectable temporarily so that I don't accidentally move it around even more. I have a few more things to wire, and some aesthetic design after which I think I'm going to make the robot first drivable via a ps5 controller, and later on add autonomous capability, I was going to have it controlled via a phone before but since I have an esp32 now, I can use this instead. 








### Recording Links

- https://lookout.hackclub.com/api/media/96abe312-690b-4622-8003-6feff6894c6f/video.mp4

## Entry 19
- ID: 13068
- Author: Diamond_0608
- Created At: 2026-06-10T18:24:44Z
**NOTE:** 53min tracked
1 recording
### Content

I decided I should definitely rename all the bodies and components right after I finish the wiring, since I spent a solid 5 minutes just looking for the front plate just to know where the hole for the ultrasound wires was which is obviously ridiculously inneficient. I wired the ultrasound sensor, the esps together and screwed down the esp. I decided to model all the lidar stuff after I actually finished the lidar code and decisions and stuff way later down the road. I'm spending every breathing moment that I'm free on this project and its making me feel so tired, and the lack of sleep is really getting to me. I realised 5v power is an issue so I connected both the ESP32 and the ultrasonic sensor to the motor drivers 5v out in parallel to the 8266. 


 



### Recording Links

- https://lookout.hackclub.com/api/media/0ee37291-98f1-48d2-95bd-f04e70bcdd52/video.mp4

## Entry 20
- ID: 13199
- Author: Diamond_0608
- Created At: 2026-06-11T10:45:07Z
**NOTE:** 1h 12m tracked
1 recording
### Content

To start off I decided to rename all the components, since Its really hard to show and hide components when I'm manually spending so long just scrolling through components, plus it adds a level of polish to the cad file. Just my luck fusion crashed once again, and I was so happy to see a recovery file but even that was corrupted, I don't know what the hell this luck is, but I redid it nevertheless. I'm looking forward to saving the final file and not touching it until I need to cause I'm fed up of the lag and crashes, I'm going to save so frequently now. I named some of the bodies as start and end when there were just 100 mirrored parts instead of taking ridiculous time to rename each one. Next, I moved the LCD display into place and added an I2C adaptor which I still have to finish modelling but will save me a lot of pins.







### Recording Links

- https://lookout.hackclub.com/api/media/74cc546d-dc40-4fb3-a8b5-be50e270b87c/video.mp4

## Entry 21
- ID: 13277
- Author: Diamond_0608
- Created At: 2026-06-11T17:43:02Z
**NOTE:** 1h 5m tracked
1 recording
### Content

I finished the modelling for the LCD screen and its I2C adapter and then wired it to the ESP32.  I spent 5 minutes just trying to figure out why my splines weren't working right just to realise I hadn't enabled my sketches to be 3d. The only downside of using the esps is I have such a huge lack of 5v pins so I have just everything running in parallel so hopefully the current draw isn't too much. I also realised that My original plan of having the charger protruding out the back to just be able to plug it in would no longer work considering I have nowhere to put the charger so I just gave up on that idea for now.




### Recording Links

- https://lookout.hackclub.com/api/media/14fbc526-c870-4b1a-94c0-85a27ec7b44a/video.mp4

## Entry 22
- ID: 13425
- Author: Diamond_0608
- Created At: 2026-06-12T09:24:17Z
**NOTE:** 48min tracked
1 recording
### Content

So to start off for the day, I first made a Github repository for my project and started off with the readme for the project. I made the following headings: Basic questions and overview, The CAD file, Suggestions for use. There isn't really that much to talk about. The way I wrote it was by thinking of how project readmes of projects I really admire looked like, and thinking from the perspective of someone who was reading this for the first time in the sense that I had no relation to the project or skills. I tried to think of what I would like to know and in what format.
After I finish all the sections of the readme that I can currently, I'll move on to the schematic diagrams and BOM as well as the code.






### Recording Links

- https://lookout.hackclub.com/api/media/7088855f-bf71-424d-a04b-4f6a9b163b43/video.mp4

## Entry 23
- ID: 13441
- Author: Diamond_0608
- Created At: 2026-06-12T11:11:39Z
**NOTE:** 48min tracked
1 recording
### Content

I updated the ReadMe with some more information pertaining to the CAD file, code and I made a complete guide on how to build it as well. I also spoke about what should be changed, and what people can modify if they're making the project on their own. I improved previous headings by filling in the gaps that I realised were present after I started talking about the build. Now anyone can build the project by just getting the materials and sourcing the ReadMe. I have to add a BOM and photos of the CAD model to the repo which I will do next log, and I also realised that I forgot to make the holes and fasteners for the motors to the side panel.




### Recording Links

- https://lookout.hackclub.com/api/media/f6e05d1f-f2a7-45f7-b211-679832c173a5/video.mp4

## Entry 24
- ID: 13508
- Author: Diamond_0608
- Created At: 2026-06-12T17:24:23Z
**NOTE:** 2h 2m tracked
2 recordings
### Content

The first thing I did was I fixed some mistakes in the CAD file, to make sure it was perfect, like missing screws, misaligned components and holes, and other tiny details that were messing up the work. Due to the base plate moving around a lot of the screws were misaligned, so I did my best to rectify that. For some reason I couldn't manually move the components because of joints, yet they still got messed up and didn't move with the joint which was interesting. A wire also went straight throw the motor driver so I had to go back and fix that. Another thing I did was make some aesthetic changes, cause I realised that the body could do with some paint work. However, choosing the colours and everything was a bit difficult since I lack any aethetic taste really. The colour options on fusion are a bit lacking as well. I added some more detailing and added a little guy that some people may recognise (SOUUUPPPP!!!) . I tried to make a honeycomb type pattern on the front number plate as well (That proved difficult with the size of the honeycombs and the size of the pattern that I wanted my fusion crashed so yay, luckily this time the recovery file actually worked. So then I made the honeycombs much larger so that it was easier to make).  All that just to decide the honeycombs don't look the best and leave only 2.
After this I took some photos to add to the Github repo.
Then I also added the 3d files to the repo. I couldn't figure out how to add folders so that's something I'll figure out later.














### Recording Links

- https://lookout.hackclub.com/api/media/f9434e5a-92d3-475b-b4c3-f2007766f942/video.mp4
- https://lookout.hackclub.com/api/media/45f49cf9-59db-44eb-8b97-b862283e2a5f/video.mp4

## Entry 25
- ID: 13702
- Author: Diamond_0608
- Created At: 2026-06-13T12:26:26Z
**NOTE:** 
2h 11m tracked
1 recording
### Content

Today is the day we finally start out with the schematics!
I created the file and then immediately realised I have none of the necessary symbols so I stopped the recording, and just downloaded it all first. The absolute first thing I did was change the autosave time to 3 minutes since I didn't want the same thing as the fusion crashes to happen. I downloaded nodemcu esp32 and esp8266s online as well as the rfid reader and lcd screens. I realised I'd have to custom make the motor driver, I2C adaptor and the rest I could just add generic components. I hope lookout doesn't capture audio cause my spotify wasn't working and I started singing to myself instead. For custom making the symbols for some parts, luckily I had the actual components on hand. Unfortunately, this is my first time using Kicad so the quality of work was, let's just say lacking. I have genuinely no idea what I'm doing and I'm cooking up some nonsensical looking stuff, but honestly this is the extent of my ability. Hopefully I learn through this. I tried my best to just make it look exactly like what was right infront of me, but one mistake I made was not making the symbol  big enough which ended up with some components on the board of various sizes looking exactly the same. Like a genius I made the pins manually not realising you should do that with the pin add command, after I inserted all the pins I realised that by convention they should be inverted. The learning curve for this part is really steep to say the least. I tried to keep the placement of the symbols as accurate as I could to what it would actually be. After I moved all the stuff into the main file (Except the I2C, I realised I imported the wrong LED screen as well so I have to custom make that too) , I stopped recording for the day to go take a break.












### Recording Links

- https://lookout.hackclub.com/api/media/72ffb380-c348-472b-8635-f80f30c57528/video.mp4

## Entry 26
- ID: 13731
- Author: Diamond_0608
- Created At: 2026-06-13T14:32:56Z
**NOTE:** 
56min tracked
1 recording
### Content

I made the I2C Adapter and the LCD screen's schematic diagram. I realised though that I had lost my LCD screen which was a little unfortunate. While I was making the schematic, I realised, why use yellow as the background colour instead of the actual colour? I tried to also get the internal parts to have their own colour, I didnt realise that it overlays the more intense colour over it. After importing the symbols in though I realised that it looked horrendous and the uniformity was why it was all yellow. My scaling may be a bit odd though for the project the component sizes really aren't accurate, but since they're 3d modeled it doesn't really matter since I know the space won't be an issue. My perfectionism made me take a really long time just to make all the internal components white to distinguish it from the rest of the body. Atleast all the symbols are imported now. I came to the unfortunate conclusion that I was wasting so much time in colour picker when I could have just picked the defined colour from the next tab. I also love saving the file and not seeing it lag out like the CAD files.







### Recording Links

- https://lookout.hackclub.com/api/media/4fb9efff-f470-4486-9643-7d2ac874847a/video.mp4

## Entry 27
- ID: 13786
- Author: Diamond_0608
- Created At: 2026-06-13T18:23:05Z
**NOTE:** 1h 5m tracked
1 recording
### Content

I started wiring the components together, I tried to follow the wiring from the CAD, but some components are slightly innacurate and I also realised that my ESP32 was a WROOM32 in the CAD and a NodeMCU one in the schematic, good thing I added the don't follow the CAD wiring and only use as a reference in the README.md I guess. I'm doing my best to learn standard practise and not just do whatever I want, but having zero knowledge, it's a bit hard. The CAD is still really usefull though, since it saves me quite a lot of thinking cause some stuff is already planned out, and I know how feasible it would be. Yet despite all that CAD work, I made some very very bad errors particularly I didn't realise that my motor driver doesn't have a 5v out pin, which is very problematic for obvious reasons. So now I need to go and buy a buck converter as well for this project just to be able to connect to my esps. My knowledge of diagrams is so limited I didn't even know what switch to use. The file started getting too close without even 1/4th of the wires needed so I had to change the configuration to an A3 sheet and now I have to move all the components one by one. Which is a process I started but didn't finish. In this log though I managed a decent amount of wiring, though it will all dissapear now that I have to delete it all and move everything. I did figure out the basic logic I would need for the buck converter though.






### Recording Links

- https://lookout.hackclub.com/api/media/df66874b-de26-4fed-8394-7631ad34f1ec/video.mp4

## Entry 28
- ID: 13898
- Author: Diamond_0608
- Created At: 2026-06-14T05:53:14Z
**NOTE:** 
1h 15m tracked
1 recording
### Content

Started out by optimising the placement of symbols in the schematic to make the wires look tidy. I almost miscalculated the buck converter and set it to 5V to fry my esps. I realised I need 1 converter to 5V and 1 to get me to 3.3V. Then I realised I only need to step it down to 3.3V and I can use the ESP's VIN pins for the 5V outputs, and that way I'm maintaining uniform logic as well. I realised that converting this voltage isn't as easy as I thought.  But then I found a voltage converter that while slightly more expensive would be way safer than my nonsense. I just had to make another custom symbol for that. I tried to even add in the LEDS in the buck converter to the symbol but it wouldn't fit. At this point I've rethought and redone the wiring like 5 times, so the all in one buck converter seems like a great option since I don't want to fry my ESPs and have to buy new ones. While the buck converter and logic has been mostly fixed, I still have to get around to doing the wiring all over again.






### Recording Links

- https://lookout.hackclub.com/api/media/cc6b6ea9-3bf7-4461-9c8d-c1aedbfb6e52/video.mp4

## Entry 29
- ID: 13919
- Author: Diamond_0608
- Created At: 2026-06-14T08:52:48Z
**NOTE:** 
1h 21m tracked
1 recording
### Content

Started off with the wiring, and the new buck converter really simplified a lot of the work as well. Having the increased page size also gave me a lot of room to work with. With the motor driver I'm using, both the motors on one side connect to the same pinouts. The NODEMCU ESP32 diagram does differ slightly from the one I have, which I realised after wiring once again when I actually cross referenced it. So I once again custom made the symbol for it and now I have to redo the wiring. The way stuff was arranged in the symbol kept stopping me from being able to fill in the internal circles which really bugged me. Having a timeline like in fusion would be so helpful.







### Recording Links

- https://lookout.hackclub.com/api/media/f74f341e-05dd-4cb8-b358-770958fa831e/video.mp4

## Entry 30
- ID: 14004
- Author: Diamond_0608
- Created At: 2026-06-14T15:27:42Z
**NOTE:** 43min tracked
1 recording
### Content

Realised even my ESP8266 differs from the one in the symbol, I think NODEMCU makes a few different versions, so I just made my own symbol again. I'm spending so much time on the symbols at this point but I'd rather be safe than sorry. As always having the physical component to visually see and draw out is so helpful. The alignment of the pins and the circles came out perfectly this time.
I realised that filling in all the internal things white wasn't perfectionism it was stupidity since I could have just made a white one then duplicated it, but too late now. The ESP8266 was perfect until I realised I accidentally made it multiple time the size it should have been.







### Recording Links

- https://lookout.hackclub.com/api/media/69fbe5b2-8bae-4de7-a991-57911064fd8f/video.mp4

## Entry 31
- ID: 14200
- Author: Diamond_0608
- Created At: 2026-06-15T09:12:12Z
**NOTE:**52min tracked
1 recording
### Content

I continued with the wiring, connected the ESPs together and the numpad to the esp. My wiring in the CAD and the schem is different, but it's written in the readme that the schematic should exclusively be followed, and regardless the difference can be easily tweaked in the code if someone follows something different. The I2C on my LCD saves me from having to use a logic shifter to connect it to my ESP. I connected the LCD's I2C to the ESP8266. I tried to use the default SCL and SDA pins, but again that would just be a quick code debug and fix.  I realised I was placing no connect flags everywhere there was a wire without a junction which apparently isn't what you're supposed to do, so I had to go delete all of them.I mostly finished the wiring, so I'll probably be moving to the code soon.







### Recording Links

- https://lookout.hackclub.com/api/media/e77e3cce-bb2e-45e7-ad99-ccb37da17e6b/video.mp4

## Entry 32
- ID: 14231
- Author: Diamond_0608
- Created At: 2026-06-15T12:13:44Z
**NOTE:** 1h 8m tracked
1 recording
### Content

I spent an embarrasing amount of time trying to create a folder in GitHub since I'm not really familiar with it. Once I did that, I organised my files into folders. My lack of knowledge is genuinely embarrasing, but I guess we all have to start somewhere. I also exported the BOM from KiCad to use as a starting point as well as the schematic as a pdf and put it in the GitHub. I managed to add the full 3d files to GitHub as well instead of just the links using the app. I then got to work on the BOM. I also took the BOM from fusion to help. I'll update the ReadMe with this as well as more detailed wiring instructions as well.  I have some more work on the BOM to do, then after the ReadMe I'll get to work on the code.






### Recording Links

- https://lookout.hackclub.com/api/media/8911cdc6-9d4b-4d8f-92dd-959408c6d3a0/video.mp4

## Entry 33
- ID: 14263
- Author: Diamond_0608
- Created At: 2026-06-15T15:56:58Z
**NOTE:** 
58min tracked
1 recording
### Content

Continued with the BOM, added pricing and links to the product and also added notes mostly pertaining to whether people can not use that component and customise it. When I exported to CSV, I lost not only all my formatting but the hyperlinks, so I guess it's a good thing I caught that in time.  I decided to put an xlsx as well as a csv just incase. I guess now it's time to move onto the firmware.





### Recording Links

- https://lookout.hackclub.com/api/media/37908bd0-765f-452f-b679-61c7d5bfdf42/video.mp4

## Entry 34
- ID: 14499
- Author: Diamond_0608
- Created At: 2026-06-16T11:13:09Z
**NOTE:** 
57min tracked
1 recording
### Content

Started off with the firmware today, but first I included the modules needed for the ESP32 components and then cross referenced each of my pins on the ESP32 with an online pinout version so I could check the GPIO pin numbers to be able to code it. Luckily most of the pins correspond to their Digital pin numbers so for those pins it was quite easy to define variables. Hopefully messed up pin numbering or functions won't be too hard to fix though. My lack of coding ability without AI though is making progress really difficult.  I did have to use gemini to make it teach me since I was really confused.  I'm trying my hardest to not use googled/ai generated code and learn it completely but god is progress going slow.




### Recording Links

- https://lookout.hackclub.com/api/media/b0b8d3f2-1517-46fc-b528-8d29370560bc/video.mp4

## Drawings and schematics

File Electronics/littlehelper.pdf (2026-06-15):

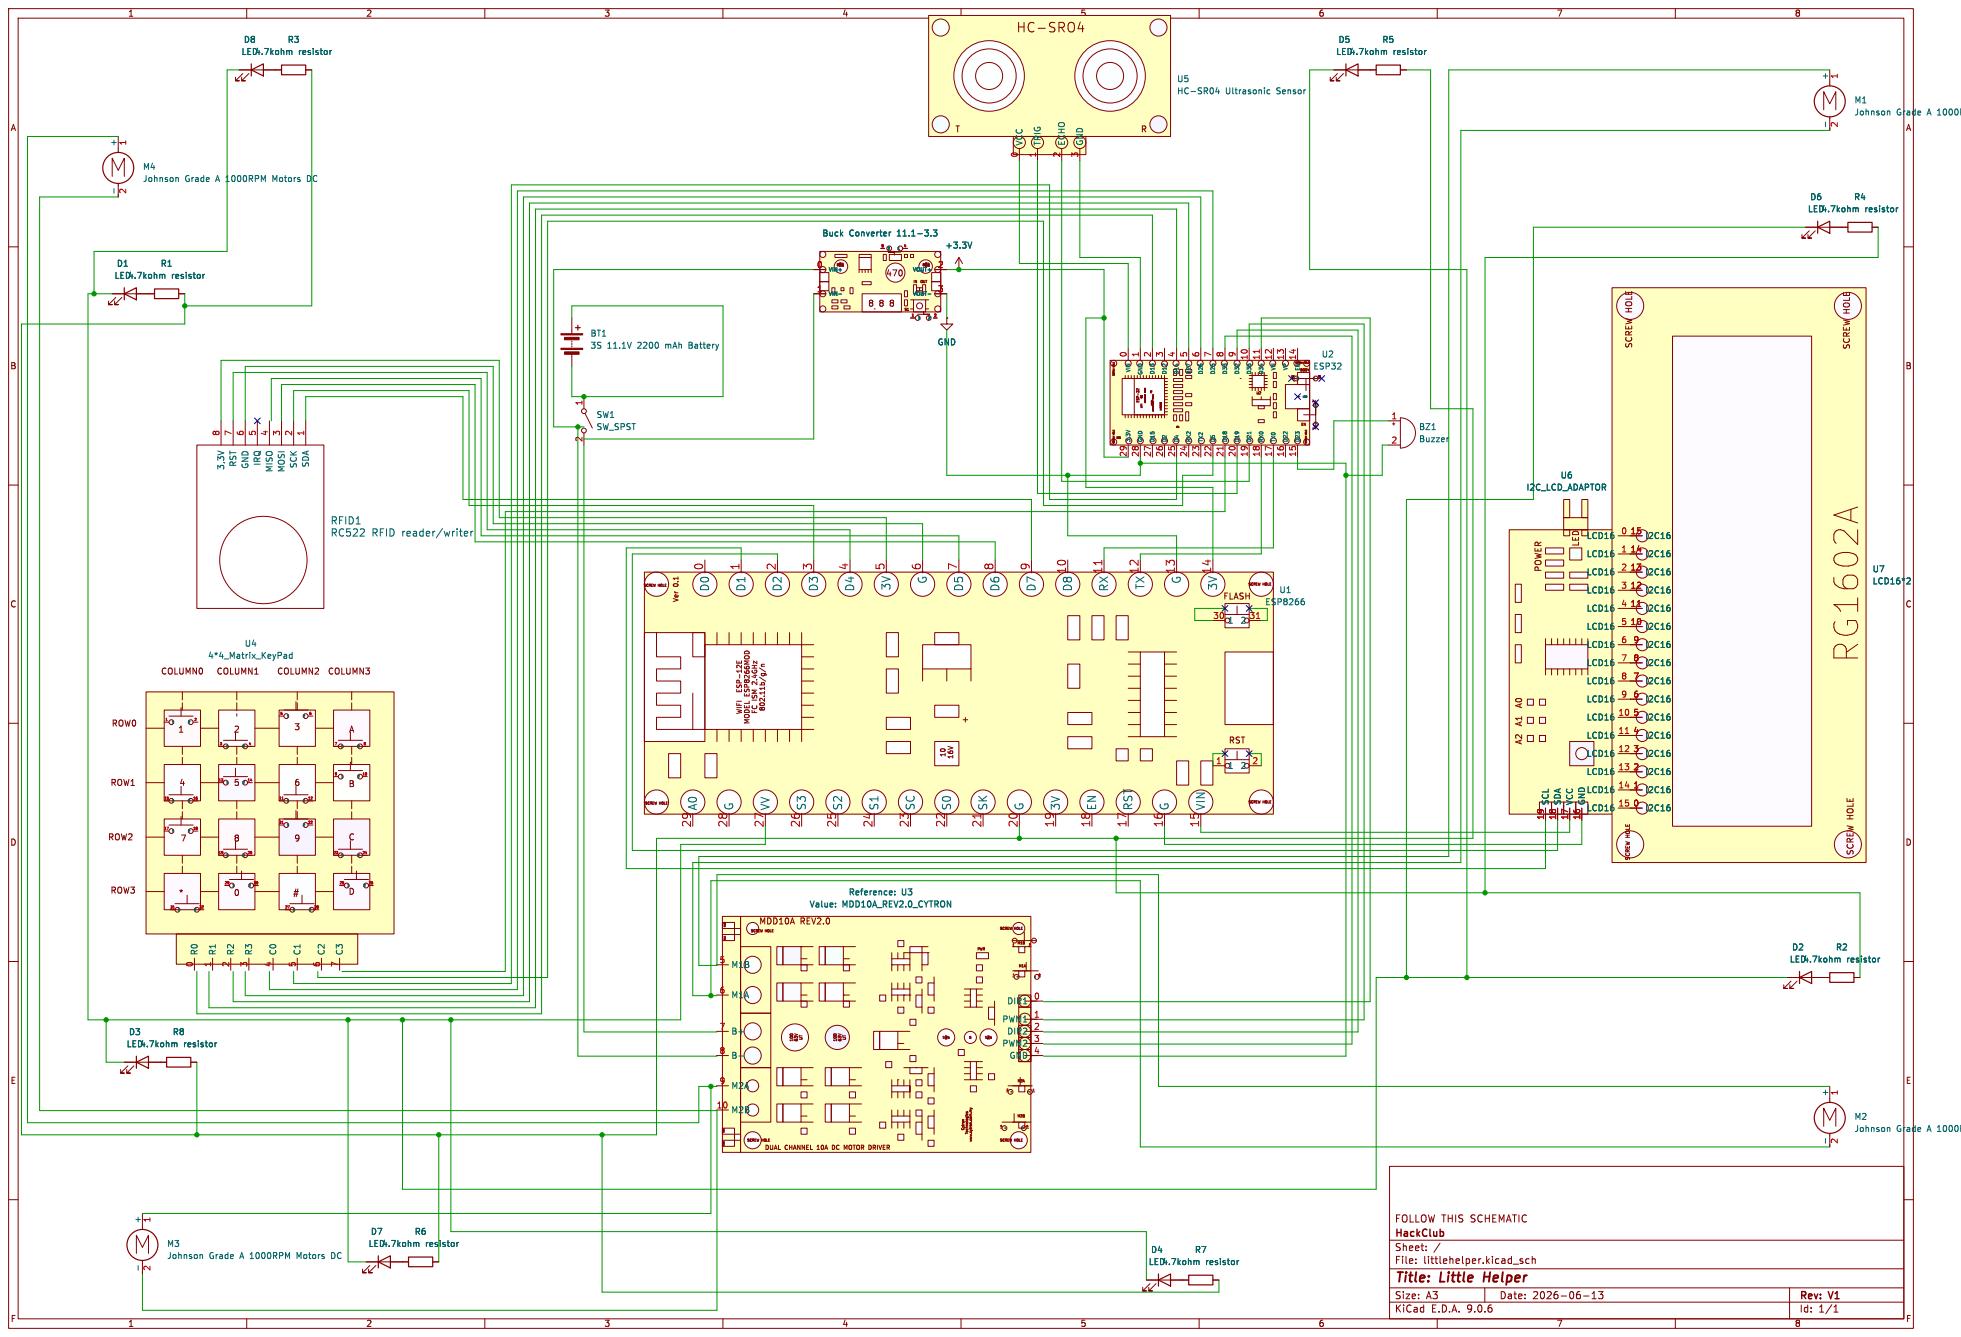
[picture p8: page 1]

Johnson Grade A 1000RPM Motors DC

www.cytron.com.my 331 PWR 47

UT DUAL CHANNEL 10A DC MOTOR DRIVER 100

FOLLOW THIS SCHEMATIC
Id: 1/1 Title: Little Helper File: littlehelper.kicad_sch Sheet: / HackClub

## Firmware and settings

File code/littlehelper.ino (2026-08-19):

#include <Bluepad32.h>
#include <Keypad.h>

// ============================================================
// MOTOR PINS
// ============================================================

#define DIR1 2
#define PWM1 15

#define DIR2 32
#define PWM2 33

// ============================================================
// ULTRASONIC + BUZZER
// ============================================================

#define TRIG   19
#define ECHO   21
#define BUZZER 23

// ============================================================
// ESP32 <-> ESP8266 UART2
//
// ESP32 GPIO17 TX2 -> ESP8266 RX GPIO3
// ESP32 GPIO16 RX2 <- ESP8266 TX GPIO1
// ============================================================

#define ESP_RX 16
#define ESP_TX 17

HardwareSerial ESPSerial(2);

// ============================================================
// KEYPAD
//
// Experimentally confirmed electrical mapping:
//
// 1 = GPIO27 <-> GPIO18
// 2 = GPIO14 <-> GPIO18
// 3 = GPIO13 <-> GPIO18
// A = GPIO5  <-> GPIO18
//
// 4 = GPIO27 <-> GPIO4
// 5 = GPIO14 <-> GPIO4
// 6 = GPIO13 <-> GPIO4
// B = GPIO5  <-> GPIO4
//
// 7 = GPIO27 <-> GPIO25
// 8 = GPIO14 <-> GPIO25
// 9 = GPIO13 <-> GPIO25
// C = GPIO5  <-> GPIO25
//
// * = GPIO27 <-> GPIO26
// 0 = GPIO14 <-> GPIO26
// # = GPIO13 <-> GPIO26
// D = GPIO5  <-> GPIO26
// ============================================================

byte rowPins[4] = {
  27,
  14,
  13,
  5
};

byte colPins[4] = {
  18,
  4,
  25,
  26
};

char keys[4][4] = {

  {'1', '4', '7', '*'},

  {'2', '5', '8', '0'},

  {'3', '6', '9', '#'},

  {'A', 'B', 'C', 'D'}
};

Keypad keypad = Keypad(
  makeKeymap(keys),
  rowPins,
  colPins,
  4,
  4
);

// ============================================================
// CONTROLLER
// ============================================================

ControllerPtr myController = nullptr;

// ============================================================
// AUTHENTICATION STATE
// ============================================================

bool cardOK = false;
bool unlocked = false;

String pin = "";

// ============================================================
// SAFETY
// ============================================================

bool obstacleEnabled = true;
bool obstacleActive = false;

bool prevCross = false;
bool prevCircle = false;
bool prevTriangle = false;

// ============================================================
// DRIVE
// ============================================================

int throttle = 0;
int steer = 0;

// ============================================================
// BUZZER
// ============================================================

void beep(int duration) {

  // Don't interrupt the continuous obstacle alarm.
  if (obstacleActive)
    return;

  digitalWrite(BUZZER, HIGH);
  delay(duration);
  digitalWrite(BUZZER, LOW);
}

void successBeep() {

  if (obstacleActive)
    return;

  digitalWrite(BUZZER, HIGH);
  delay(120);

  digitalWrite(BUZZER, LOW);
  delay(60);

  digitalWrite(BUZZER, HIGH);
  delay(180);

  digitalWrite(BUZZER, LOW);
}

void errorBeep() {

  if (obstacleActive)
    return;

  digitalWrite(BUZZER, HIGH);
  delay(100);

  digitalWrite(BUZZER, LOW);
  delay(80);

  digitalWrite(BUZZER, HIGH);
  delay(100);

  digitalWrite(BUZZER, LOW);
}

// ============================================================
// MOTORS
// ============================================================

void motor(
  int dirPin,
  int pwmPin,
  int speed
) {

  speed = constrain(
    speed,
    -255,
    255
  );

  digitalWrite(
    dirPin,
    speed >= 0 ? HIGH : LOW
  );

  analogWrite(
    pwmPin,
    abs(speed)
  );
}

void stopMotors() {

  analogWrite(
    PWM1,
    0
  );

  analogWrite(
    PWM2,
    0
  );
}

// ============================================================
// LOCK BOT
// ============================================================

void lockBot() {

  cardOK = false;
  unlocked = false;

  pin = "";

  throttle = 0;
  steer = 0;

  stopMotors();

  ESPSerial.println("LOCK");

  Serial.println();
  Serial.println("================================");
  Serial.println("BOT LOCKED");
  Serial.println("================================");
}

// ============================================================
// CONTROLLER CONNECTED
// ============================================================

void onConnectedController(
  ControllerPtr ctl
) {

  myController = ctl;

  Serial.println(
    "CONTROLLER CONNECTED"
  );
}

void onDisconnectedController(
  ControllerPtr ctl
) {

  if (myController == ctl) {

    myController = nullptr;

    throttle = 0;
    steer = 0;

    stopMotors();

    Serial.println(
      "CONTROLLER DISCONNECTED"
    );
  }
}

// ============================================================
// ESP8266 COMMUNICATION
// ============================================================

void checkESP8266() {

  if (!ESPSerial.available())
    return;

  String command =
    ESPSerial.readStringUntil('\n');

  command.trim();

  if (command.length() == 0)
    return;

  Serial.print(
    "ESP8266: "
  );

  Serial.println(command);

  // ----------------------------------------------------------
  // RFID ACCEPTED
  // ----------------------------------------------------------

  if (command == "CARD_OK") {

    cardOK = true;
    unlocked = false;
    pin = "";

    Serial.println(
      "RFID ACCEPTED"
    );

    successBeep();
  }

  // ----------------------------------------------------------
  // LOCK
  // ----------------------------------------------------------

  else if (command == "LOCK") {

    cardOK = false;
    unlocked = false;
    pin = "";

    throttle = 0;
    steer = 0;

    stopMotors();

    Serial.println(
      "LOCK RECEIVED"
    );
  }

  // ----------------------------------------------------------
  // UNLOCK
  // ----------------------------------------------------------

  else if (command == "UNLOCK") {

    unlocked = true;
    cardOK = true;

    pin = "";

    Serial.println(
      "BOT UNLOCKED"
    );

    successBeep();
  }

  // ----------------------------------------------------------
  // WRONG PIN
  // ----------------------------------------------------------

  else if (command == "PIN_FAIL") {

    pin = "";

    Serial.println(
      "PIN FAILED"
    );

    errorBeep();
  }
}

// ============================================================
// KEYPAD
// ============================================================

void checkKeypad() {

  char key = keypad.getKey();

  if (!key)
    return;

  // Every key gets a short beep.
  beep(60);

  Serial.print(
    "KEY PRESSED: "
  );

  Serial.println(key);

  // ==========================================================
  // *
  // ==========================================================

  if (key == '*') {

    // If currently driving, * locks the bot.
    if (unlocked) {

      Serial.println(
        "STAR -> LOCK"
      );

      lockBot();

      return;
    }

    // RFID accepted -> start PIN entry.
    if (cardOK) {

      pin = "";

      Serial.println(
        "ENTER PIN"
      );

      ESPSerial.println(
        "ENTER_PIN"
      );

      return;
    }

    // No RFID yet.
    Serial.println(
      "NO RFID CARD"
    );

    ESPSerial.println(
      "NEED_CARD"
    );

    return;
  }

  // ==========================================================
  // #
  // ==========================================================

  if (key == '#') {

    if (!cardOK) {

      Serial.println(
        "NO RFID CARD"
      );

      ESPSerial.println(
        "NEED_CARD"
      );

      return;
    }

    if (unlocked) {

      Serial.println(
        "BOT ALREADY UNLOCKED"
      );

      return;
    }

    pin = "";

    Serial.println(
      "PIN CLEARED"
    );

    ESPSerial.println(
      "PIN_CLEAR"
    );

    return;
  }

  // ==========================================================
  // NUMBER
  // ==========================================================

  if (
    key >= '0' &&
    key <= '9'
  ) {

    if (!cardOK) {

      Serial.println(
        "NO RFID CARD"
      );

      ESPSerial.println(
        "NEED_CARD"
      );

      return;
    }

    if (unlocked) {

      Serial.println(
        "BOT ALREADY UNLOCKED"
      );

      return;
    }

    if (pin.length() < 4) {

      pin += key;

      Serial.print(
        "PIN: "
      );

      for (
        unsigned int i = 0;
        i < pin.length();
        i++
      ) {

        Serial.print('*');
      }

      Serial.println();

      ESPSerial.print(
        "PIN_DIGIT:"
      );

      ESPSerial.println(key);
    }

    // Four digits entered.
    if (pin.length() == 4) {

      // ======================================================
      // PIN = 1234
      // ======================================================

      if (pin == "1234") {

        Serial.println(
          "CORRECT PIN"
        );

        unlocked = true;

        pin = "";

        ESPSerial.println(
          "UNLOCK"
        );

        successBeep();
      }

      else {

        Serial.println(
          "WRONG PIN"
        );

        pin = "";

        ESPSerial.println(
          "PIN_FAIL"
        );

        errorBeep();
      }
    }

    return;
  }

  // ==========================================================
  // A / B / C / D
  // ==========================================================

  if (
    key == 'A' ||
    key == 'B' ||
    key == 'C' ||
    key == 'D'
  ) {

    Serial.print(
      "INVALID PIN KEY: "
    );

    Serial.println(key);

    ESPSerial.println(
      "KEY_INVALID"
    );

    return;
  }
}

// ============================================================
// CONTROLLER
// ============================================================

void checkController() {

  if (
    !myController ||
    !myController->isConnected()
  ) {

    throttle = 0;
    steer = 0;

    stopMotors();

    return;
  }

  bool cross =
    myController->a();

  bool circle =
    myController->b();

  bool triangle =
    myController->x();

  // ==========================================================
  // X / CROSS = SAFETY TOGGLE
  // ==========================================================

  if (
    cross &&
    !prevCross
  ) {

    obstacleEnabled =
      !obstacleEnabled;

    if (!obstacleEnabled) {

      obstacleActive = false;

      digitalWrite(
        BUZZER,
        LOW
      );

      Serial.println(
        "SAFETY: OFF"
      );

      ESPSerial.println(
        "SAFE_OFF"
      );
    }

    else {

      Serial.println(
        "SAFETY: ON"
      );

      ESPSerial.println(
        "SAFE_ON"
      );
    }
  }

  // ==========================================================
  // O / CIRCLE = LOCK
  // ==========================================================

  if (
    circle &&
    !prevCircle
  ) {

    Serial.println(
      "CIRCLE -> LOCK"
    );

    lockBot();
  }

  // ==========================================================
  // TRIANGLE = MANUAL BUZZER
  // ==========================================================

  if (
    triangle &&
    !prevTriangle
  ) {

    Serial.println(
      "TRIANGLE -> BEEP"
    );

    beep(200);
  }

  prevCross = cross;
  prevCircle = circle;
  prevTriangle = triangle;

  // ==========================================================
  // DRIVE INPUT
  // ==========================================================

  throttle =
    map(
      myController->axisY(),
      -511,
      512,
      -255,
      255
    );

  steer =
    map(
      myController->axisRX(),
      -511,
      512,
      -255,
      255
    );

  if (
    abs(throttle) < 20
  )
    throttle = 0;

  if (
    abs(steer) < 20
  )
    steer = 0;
}

// ============================================================
// ULTRASONIC
// ============================================================

void checkUltrasonic() {

  static unsigned long lastCheck = 0;

  if (
    millis() - lastCheck < 100
  )
    return;

  lastCheck = millis();

  // Trigger pulse
  digitalWrite(
    TRIG,
    LOW
  );

  delayMicroseconds(2);

  digitalWrite(
    TRIG,
    HIGH
  );

  delayMicroseconds(10);

  digitalWrite(
    TRIG,
    LOW
  );

  unsigned long duration =
    pulseIn(
      ECHO,
      HIGH,
      30000
    );

  int distance =
    duration
      ? duration / 58
      : 0;

  // ==========================================================
  // SAFETY OFF
  // ==========================================================

  if (!obstacleEnabled) {

    obstacleActive = false;

    digitalWrite(
      BUZZER,
      LOW
    );

    return;
  }

  // ==========================================================
  // SAFETY ON
  // ==========================================================

  bool detected =
    distance > 0 &&
    distance < 15;

  bool previousObstacle =
    obstacleActive;

  obstacleActive =
    detected;

  // Continuous obstacle buzzer.
  digitalWrite(
    BUZZER,
    obstacleActive ? HIGH : LOW
  );

  // Only report changes.
  if (
    obstacleActive &&
    !previousObstacle
  ) {

    Serial.print(
      "OBSTACLE: "
    );

    Serial.print(
      distance
    );

    Serial.println(
      " cm"
    );

    ESPSerial.println(
      "OBSTACLE"
    );
  }

  else if (
    !obstacleActive &&
    previousObstacle
  ) {

    Serial.println(
      "OBSTACLE CLEAR"
    );

    ESPSerial.println(
      "CLEAR"
    );
  }
}

// ============================================================
// DRIVE
// ============================================================

void drive() {

  // Must be unlocked.
  if (!unlocked) {

    stopMotors();

    return;
  }

  // Safety obstacle stop.
  if (obstacleActive) {

    stopMotors();

    return;
  }

  int left =
    constrain(
      throttle - steer,
      -255,
      255
    );

  int right =
    constrain(
      throttle + steer,
      -255,
      255
    );

  motor(
    DIR1,
    PWM1,
    left
  );

  motor(
    DIR2,
    PWM2,
    right
  );
}

// ============================================================
// SETUP
// ============================================================

void setup() {

  Serial.begin(115200);

  // ----------------------------------------------------------
  // UART2
  // ----------------------------------------------------------

  ESPSerial.begin(
    115200,
    SERIAL_8N1,
    ESP_RX,
    ESP_TX
  );

  // ----------------------------------------------------------
  // MOTOR PINS
  // ----------------------------------------------------------

  pinMode(
    DIR1,
    OUTPUT
  );

  pinMode(
    PWM1,
    OUTPUT
  );

  pinMode(
    DIR2,
    OUTPUT
  );

  pinMode(
    PWM2,
    OUTPUT
  );

  // ----------------------------------------------------------
  // ULTRASONIC
  // ----------------------------------------------------------

  pinMode(
    TRIG,
    OUTPUT
  );

  pinMode(
    ECHO,
    INPUT
  );

  digitalWrite(
    TRIG,
    LOW
  );

  // ----------------------------------------------------------
  // BUZZER
  // ----------------------------------------------------------

  pinMode(
    BUZZER,
    OUTPUT
  );

  digitalWrite(
    BUZZER,
    LOW
  );

  // ----------------------------------------------------------
  // MOTORS OFF
  // ----------------------------------------------------------

  stopMotors();

  // ----------------------------------------------------------
  // BLUEPAD32
  // ----------------------------------------------------------

  BP32.setup(
    &onConnectedController,
    &onDisconnectedController
  );

  Serial.println();
  Serial.println(
    "================================"
  );
  Serial.println(
    "       LITTLE HELPER ESP32"
  );
  Serial.println(
    "================================"
  );
  Serial.println(
    "UART2 RX = GPIO16"
  );
  Serial.println(
    "UART2 TX = GPIO17"
  );
  Serial.println(
    "TRIG = GPIO19"
  );
  Serial.println(
    "ECHO = GPIO21"
  );
  Serial.println(
    "BUZZER = GPIO23"
  );
  Serial.println(
    "KEYPAD READY"
  );
  Serial.println(
    "X = SAFETY ON/OFF"
  );
  Serial.println(
    "O = LOCK"
  );
  Serial.println(
    "TRIANGLE = BEEP"
  );
  Serial.println(
    "================================"
  );
}

// ============================================================
// LOOP
// ============================================================

void loop() {

  BP32.update();

  checkESP8266();

  checkKeypad();

  checkUltrasonic();

  checkController();

  drive();
}

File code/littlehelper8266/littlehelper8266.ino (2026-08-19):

#include <SPI.h>
#include <MFRC522.h>
#include <Wire.h>
#include <LiquidCrystal_I2C.h>

// ============================================================
// RFID
// ============================================================

#define RFID_SS   15   // D8
#define RFID_RST  0    // D3

MFRC522 rfid(RFID_SS, RFID_RST);

// ============================================================
// LCD
// ============================================================

#define SDA_PIN 4      // D2
#define SCL_PIN 5      // D1

LiquidCrystal_I2C lcd(0x27, 16, 2);

// ============================================================
// AUTH
// ============================================================

byte allowedUID[4] = {
  0x67, 0x3C, 0xD5, 0xE7
};

const char* PIN_CODE = "1234";

enum State {
  LOCKED,
  CARD_OK,
  UNLOCKED
};

State state = LOCKED;

String lastMessage = "";

// ============================================================
// LCD
// ============================================================

void showMsg(String a, String b = "") {

  String s = a + "|" + b;

  if (s == lastMessage)
    return;

  lastMessage = s;

  lcd.clear();

  lcd.setCursor(0, 0);
  lcd.print(a);

  lcd.setCursor(0, 1);
  lcd.print(b);
}

// ============================================================
// LOCK
// ============================================================

void lockBot() {

  state = LOCKED;

  Serial.println("LOCK");

  showMsg(
    "Scan RFID card",
    "to begin"
  );
}

// ============================================================
// RFID
// ============================================================

void checkRFID() {

  if (state != LOCKED)
    return;

  if (!rfid.PICC_IsNewCardPresent())
    return;

  if (!rfid.PICC_ReadCardSerial())
    return;

  Serial.print("UID: ");

  for (
    byte i = 0;
    i < rfid.uid.size;
    i++
  ) {

    if (rfid.uid.uidByte[i] < 0x10)
      Serial.print("0");

    Serial.print(
      rfid.uid.uidByte[i],
      HEX
    );

    if (i < rfid.uid.size - 1)
      Serial.print(":");
  }

  Serial.println();

  bool valid =
    rfid.uid.size == 4;

  for (
    byte i = 0;
    i < 4 && valid;
    i++
  ) {

    if (
      rfid.uid.uidByte[i] !=
      allowedUID[i]
    ) {
      valid = false;
    }
  }

  rfid.PICC_HaltA();
  rfid.PCD_StopCrypto1();

  // ----------------------------------------------------------
  // VALID CARD
  // ----------------------------------------------------------

  if (valid) {

    state = CARD_OK;

    Serial.println("CARD OK");

    showMsg(
      "Card OK",
      "Press * for PIN"
    );

    Serial.println("CARD_OK");
  }

  // ----------------------------------------------------------
  // INVALID CARD
  // ----------------------------------------------------------

  else {

    Serial.println(
      "UNKNOWN CARD"
    );

    showMsg(
      "Unknown card",
      "Try again"
    );

    delay(1200);

    showMsg(
      "Scan RFID card",
      "to begin"
    );
  }
}

// ============================================================
// ESP32 -> ESP8266
// ============================================================

void checkESP32() {

  if (!Serial.available())
    return;

  String command =
    Serial.readStringUntil('\n');

  command.trim();

  // ----------------------------------------------------------
  // LOCK
  // ----------------------------------------------------------

  if (command == "LOCK") {

    state = LOCKED;

    showMsg(
      "Scan RFID card",
      "to begin"
    );
  }

  // ----------------------------------------------------------
  // ENTER PIN
  // ----------------------------------------------------------

  else if (
    command == "ENTER_PIN"
  ) {

    if (state == CARD_OK) {

      showMsg(
        "Enter PIN:",
        ""
      );
    }
  }

  // ----------------------------------------------------------
  // PIN DIGIT
  // ----------------------------------------------------------

  else if (
    command.startsWith("PIN_DIGIT:")
  ) {

    if (state != CARD_OK)
      return;

    String digit =
      command.substring(10);

    showMsg(
      "Enter PIN:",
      "****"
    );
  }

  // ----------------------------------------------------------
  // CLEAR PIN
  // ----------------------------------------------------------

  else if (
    command == "PIN_CLEAR"
  ) {

    if (state == CARD_OK) {

      showMsg(
        "Enter PIN:",
        ""
      );
    }
  }

  // ----------------------------------------------------------
  // WRONG PIN
  // ----------------------------------------------------------

  else if (
    command == "PIN_FAIL"
  ) {

    state = CARD_OK;

    showMsg(
      "Wrong PIN!",
      "Press * to retry"
    );
  }

  // ----------------------------------------------------------
  // UNLOCK
  // ----------------------------------------------------------

  else if (
    command == "UNLOCK"
  ) {

    state = UNLOCKED;

    Serial.println(
      "UNLOCKED"
    );

    showMsg(
      "UNLOCKED",
      "Drive enabled"
    );
  }

  // ----------------------------------------------------------
  // OBSTACLE
  // ----------------------------------------------------------

  else if (
    command == "OBSTACLE"
  ) {

    if (state == UNLOCKED) {

      showMsg(
        "OBSTACLE!",
        "STOPPED"
      );
    }
  }

  // ----------------------------------------------------------
  // CLEAR
  // ----------------------------------------------------------

  else if (
    command == "CLEAR"
  ) {

    if (state == UNLOCKED) {

      showMsg(
        "UNLOCKED",
        "Drive enabled"
      );
    }
  }

  // ----------------------------------------------------------
  // SAFETY OFF
  // ----------------------------------------------------------

  else if (
    command == "SAFE_OFF"
  ) {

    if (state == UNLOCKED) {

      showMsg(
        "UNLOCKED",
        "Safety OFF"
      );
    }
  }

  // ----------------------------------------------------------
  // SAFETY ON
  // ----------------------------------------------------------

  else if (
    command == "SAFE_ON"
  ) {

    if (state == UNLOCKED) {

      showMsg(
        "UNLOCKED",
        "Drive enabled"
      );
    }
  }

  // ----------------------------------------------------------
  // NEED CARD
  // ----------------------------------------------------------

  else if (
    command == "NEED_CARD"
  ) {

    if (state == LOCKED) {

      showMsg(
        "Scan RFID card",
        "to begin"
      );
    }
  }

  // ----------------------------------------------------------
  // INVALID KEY
  // ----------------------------------------------------------

  else if (
    command == "KEY_INVALID"
  ) {

    if (state == CARD_OK) {

      showMsg(
        "Invalid key",
        "Use 0-9"
      );

      delay(700);

      showMsg(
        "Enter PIN:",
        ""
      );
    }
  }
}
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

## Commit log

2026-06-12 ReadMe Made
    I have attempted to document everything you may need to build this project, from the code and the CAD design to basic questions, common use cases , tips for building and a complete guide for building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
2026-06-12 Photos of the CAD file for Little Helper
    Just some sick photos.
2026-06-12 Added link for CAD files
    Added a link to access large CAD files on Google Drive since they're too big to upload directly to git.
2026-06-15 Deleted broken CAD&Schematics
2026-06-15 Create Link to CAD Google Drive
2026-06-15 Update Link to CAD Google Drive
2026-06-15 added cad models
2026-06-15 added BOM cost
    Updated instructions for building the bot, including cost details and wiring steps.
2026-06-15 updated bom
2026-06-20 added printables
2026-06-21 added tank track costs to bom
    [LittleHelperBOM.csv, LittleHelperBOM.xlsx]
2026-06-21 added tank track cost
2026-06-21 added the kicad schem stuff
    [littlehelper.csv, littlehelper.kicad_pcb, littlehelper.kicad_sch]
